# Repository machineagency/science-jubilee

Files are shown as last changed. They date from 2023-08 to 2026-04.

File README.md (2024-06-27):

# 🔬🧪 Science Jubilee ⚡⚙️
### Controlling Jubilees for Science!

<!-- [![Built Status](https://api.cirrus-ci.com/github/<USER>/science-jubilee.svg?branch=main)](https://cirrus-ci.com/github/<USER>/science-jubilee) -->

<!--- [![Coveralls](https://img.shields.io/coveralls/github/machineagency/science-jubilee/main.svg)](https://coveralls.io/r/machineagency/science-jubilee) --->

<!-- [![Conda-Forge](https://img.shields.io/conda/vn/conda-forge/science-jubilee.svg)](https://anaconda.org/conda-forge/science-jubilee) -->




> Use an open-source toolchanger to do science



This repository hosts files to build and control a [Jubilee](https://jubilee3d.com/index.php?title=Main_Page) for scientific applications. The core of the software is a Python interface for Jubilee to navigate labware installed in the machine. We currently provide assembly instructions, control software, and examples for various tools including OT-2 pipettes, syringes, and cameras. While these tools might cater exactly to your planned use case, they most likely will not! We share these files as a starting point rather than an endpoint: we also provide instructions for developing new tools and associated software for controlling them. We hope you will build new tools for your application and contribute them back to the community for others to use and extend 🛠️

_Check out the [Documentation](https://science-jubilee.readthedocs.io/en/latest/index.html) to get started!_

## Overview
### Hardware
This repository is designed to be used with the Jubilee platform, outfitted with tools for laboratory automation. Jubilee an open-source & extensible multi-tool motion platform—if that doesn't mean much to you, you can think of it as a 3D printer that can change its tools. You can read about [Jubilee](https://jubilee3d.com/index.php?title=Main_Page) more generally at the project page.

### Software
The software here is intended to control Jubilee from Python scripts or Jupyter notebooks to design and run experiments. The folders are organized as follows:
```
calibration/                 # notebooks to support machine & tool setup/calibration
tool_library/                # design files, assembly instructions, & configuration info for all tools & plates
src/
└── science_jubilee/
    ├── Machine.py               # jubilee machine driver
    ├── tools/
    │   ├── configs/             # all tool configs are here
    │   ├── Tool.py              # base tool class
    │   └── ...                  # all tool modules are here
    ├── decks/
    │   ├── configs/             # all deck configs are here
    │   ├── Deck.py              # base deck class
    │   └── ...                  # all deck modules are here
    └── labware/
        ├── labware_definitions/ # all labware definitions are here
        └── Labware.py           # base labware class
```

### Labware and Wetware
The basic functionality supported by this software is intended to be used with a custom deck which accommodates up to 6 standard sized microplates.

### Using science_jubilee
You can import and use `science_jubilee` modules by importing the modules you need at the top of your python file/notebook. For example, if we want to pipette using a lab automation deck, we might write:
```python
from science_jubilee.Machine import Machine                             # import machine driver
from science_jubilee.decks.LabAutomationDeck import LabAutomationDeck   # import lab automation deck module
from science_jubilee.tools.Pipette import Pipette                       # import pipette module
...                                                                     # you can import other decks/tools here, or make your own!
```
We can then make use of these modules in our code:
```python
m = Machine()                                                  # connect to your jubilee
deck = m.load_deck(deck_config_name)                           # setup your deck
tip_rack = deck.load_labware(opentrons_96_tiprack_300ul, 0)    # install an opentrons tip rack in slot 0 of the deck
pipette = Pipette(<index>, <name>, <tip_rack>, <config_file>)  # instantiate your pipette tool
m.load_tool(pipette)                                           # configure the pipette for use on the machine
...
```

<!-- pyscaffold-notes -->

## Note

This project has been set up using PyScaffold 4.5. For details and usage
information on PyScaffold see https://pyscaffold.org/.

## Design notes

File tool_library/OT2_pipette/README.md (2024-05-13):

# Opentrons OT2 Pipette
This tool can be assembled using two different tool assemblies which only differ by fabrication techniques (i.e., 3D printed only or 3D + Laser Cut)

## Wiring

For wiring we suggest using the following items:
* 1x 10-Pin (2x5) Female IDC 2.54mm Pitch [Connectors](https://www.amazon.com/gp/product/B07W5C4P6Z/ref=ppx_yo_dt_b_asin_title_o01_s00?ie=UTF8&psc=1)
* 1x 2.54mm Connectors, 10 Wire [Flat Ribbon Cable](https://www.amazon.com/gp/product/B08435GF42/ref=ppx_yo_dt_b_asin_title_o09_s00?ie=UTF8&psc=1)

For wiring information, follor the instructions found in `assembly_docs/OT2_Wiring_Diagram.pdf`

## Fabrication Files

Fabrication files for each of the two version of the tool assembly can be found in the `designs/` folder. There you can also find the tool post assembly.

## Duet Configuaration

Refer to the `duet_config/OT2_Pipette_Configuration.md` file for more information on how to update your machine's `config.g` file to control the pipettor.

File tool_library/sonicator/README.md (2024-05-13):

# Sonicator

This tool can be assembled and interfaced in different ways. You can find below a list of necessary components

## Hardware Checklist

### Sonicator Tool
* Q125 Sonicator Horn
* Sonicator Probe (various probe sizes, including pn: 4423, pn: 4422, and pn: 4435)
* Sonicator Control PCB, pn: KITVC1025 (20kHz) or pn: KITVC1045 (40kHz)
* Sonicator Wiring Harness
    * 1x [Molex: 0022552102](https://www.digikey.com/en/products/detail/molex/0022552102/303176)
    * 3x [Molex: 0016020086](https://www.digikey.com/en/products/detail/molex/0016020086/467788)
    * 1x [McMaster-Carr: 7243K117](https://www.mcmaster.com/7243K117/) for the sonicator horn wiring
    * 1x [McMaster-Carr: 7243K122](https://www.mcmaster.com/7243K122/) for the sonicator horn wiring
    * 1x [Digikey: ED10562-ND](https://www.digikey.com/en/products/detail/on-shore-technology-inc/OSTVN03A150/1588863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)

### Raspberry Pi Pico Microcontroller
One of the ways to interface with the sonicator control PCB board is using a Raspberry Pi Pico microcontroller. This solution allows the user to interface the tool through their computer directly, instead of relying on a Raspberry Pi SBC. To set up the RP2040 pico, the instructions and necessary files can be found in the `rp2040` folder.

For this solution, the following items are required:
* 1x [Raspberry Pi Pico RP2040 microcontroller](https://www.raspberrypi.com/documentation/microcontrollers/raspberry-pi-pico.html)
* 1x [Adafruit MCP4725 12-bit DAC](https://www.adafruit.com/product/935)
* 1x [Half-size Breadboard](https://www.adafruit.com/product/64), alternatively you can also purchase a [Half-size soldering breadboard](https://www.digikey.com/en/products/detail/sparkfun-electronics/PRT-12070/5230951)
* 1x [Breadboard wire bundle](https://www.adafruit.com/product/153)
* 1x [2N7000 MOSFET](https://www.digikey.com/en/products/detail/onsemi/2N7000/244278)
* 1x [100𝜇F Capacitor](https://www.amazon.com/100uF-105%C2%B0C-Aluminum-Electrolytic-Capacitor/dp/B07D6WDQMV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)
* 1x [4.7kΩ Resistor](https://www.adafruit.com/product/2783)

Below is a schematics for the assembly:
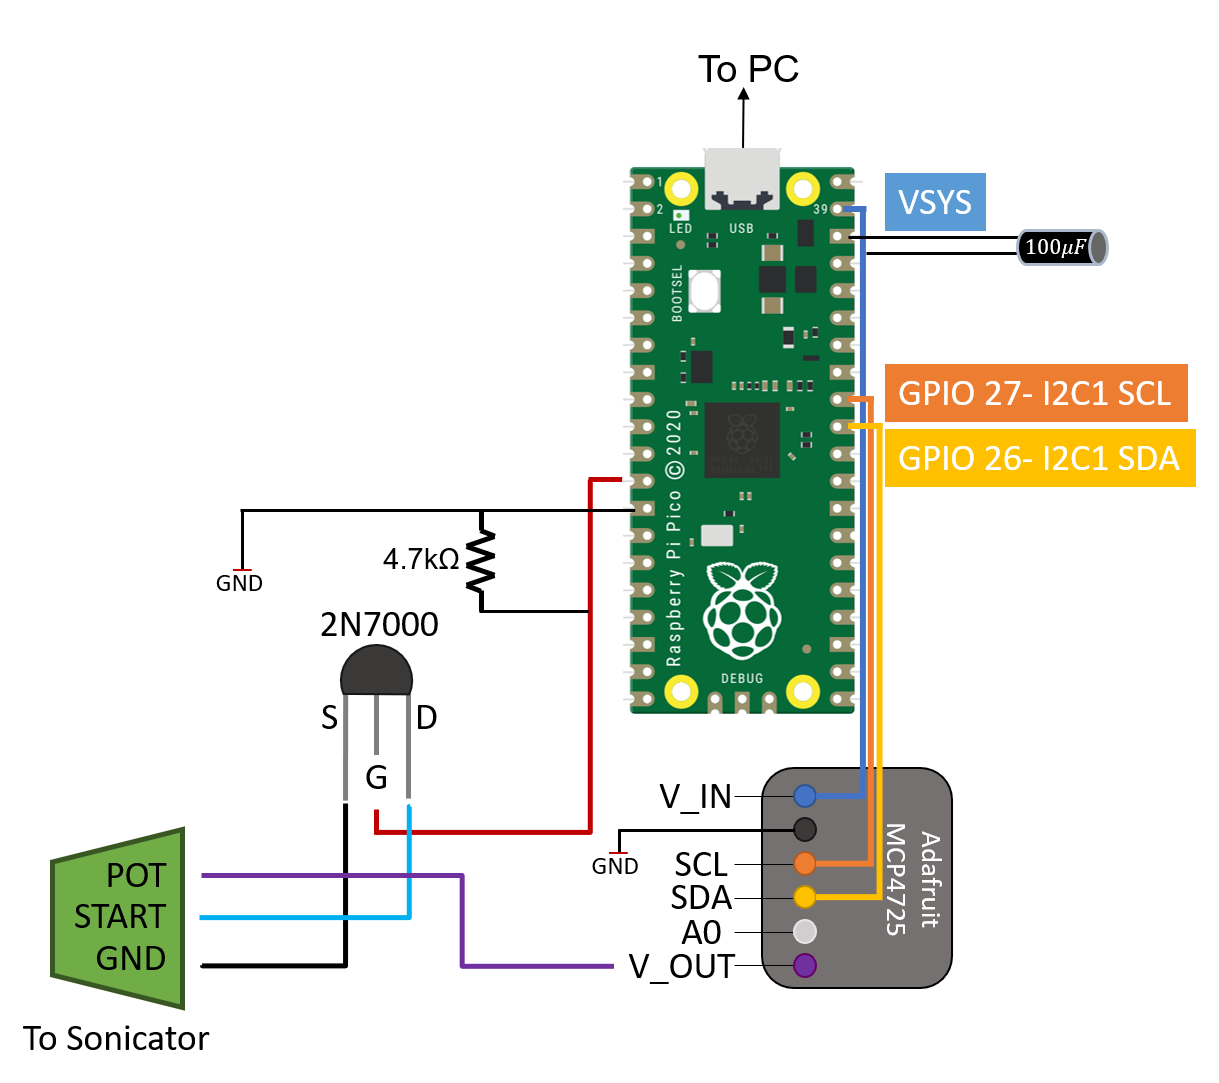
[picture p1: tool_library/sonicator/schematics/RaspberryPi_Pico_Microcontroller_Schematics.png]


### Raspberry Pi SBC and PCB Hat
If you are interfacing your Science Jubilee using a Raspberry Pi singleboard computer, you will need to order and assemble the *sonicator PCB* hat. The instructions and necessary files can be found in the `pcb_hat` folder. The Sonicator Pi Hat will be attached to the Pi and connected to the Sonicator Control PCB.
A schematics can be found [here](https://github.com/machineagency/science-jubilee/tree/main/tool_library/sonicator/schematics/RaspberryPi_PCB_Hat_Schematics.pdf)
This solution is the original imlementaiotn of this tool in combination with a Jubilee platform. This project was also known as the *Sonication Station*. The original repository is [here](https://github.com/machineagency/sonication_station).

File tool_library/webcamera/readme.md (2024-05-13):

# Raspberry Pi WebCamera

The WebCamera tool is just a Raspberry Pi Camera set up to support a livestream video over the web.
This can be used to monitor samples/objects on the deck. Alternatively, it can also be used to collect images of samples as a Tool hosted on your Jubilee.

## Necessary Hardware:
* A Raspberry Pi SBC
* Raspberry Pi camera (V2 or V3)
* An arducam pi camera HDMI extension kit along with an [hdmi cable](https://www.amazon.com/Arducam-Extension-Module-Raspberry-Specific/dp/B06XDNBM63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*)
* Hdmi cable (at least 3ft)
* Ethernet cable ( at least 3ft)

## Ring Light (Optional):
* Side emitting COB LED lights (e.g., [LED lights](https://www.amazon.com/dp/B0CG9H983Z?psc=1&ref=ppx_yo2ov_dt_b_product_details))

To control the LED lights, you can use the Duet board by plugging them into a 'fan' port. On your main Duet board you can for example `out5` or `out6` ports.
1. Cabling :

* connect the *positive LED lead* into the *"V_OUTLC2 +"* pin
* connect the *negative LED lead* into the *"out5 -"* pin

2. Duet Config

Define the LED lights into the `config.g` file of your jubilee by using the `M950` command:
`M950 P0 C"0.out5"` # P{LED index}; C{port name}

To turn on and off the light you will use the `M42` command:
`M42 P0 S0.5` # P{LED index}; S{intensity}, ranges from 0 (off) to 1 (max intensity)
    Note: this optin is alreadyimplement in the tool.WebCamera mdule. You will need to define the LED index in the tool config file and set `light=True` and `light_intensity= float` in the `capture_image()` method.

## RaspberryPi Set up

* Install raspberry pi os on a Raspberry Pi 4GB of ram should be fine - we’re just running a web server on it to stream videos
* Connect the camera using the hdmi cable extension kit. Make sure the camera works at this stage before trying to get the web server to work.
* Clone the `PI-camera-stream-flask` repo onto your raspberry pi. Brenden Pelkies’s fork has a few updates that makes it work with jubilee. [Github repository](https://github.com/brendenpelkie/pi-camera-stream-flask)
* Follow the instructions in the readme of the repo to get the camera up and running.
* Connect the raspberry pi to your local network and manually specify an IP address for it. To complete these steps, there are a lot of tutorials. [Here is one](https://www.makeuseof.com/raspberry-pi-set-static-ip/)
* Connect to your raspberry pi camera by navigating to `http:/<yourPi_IPaddress>:50001`. You should now be able to see a live feed video displayed with some buttons and a target pattern.

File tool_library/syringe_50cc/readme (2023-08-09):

this is where 50cc syringe files will be

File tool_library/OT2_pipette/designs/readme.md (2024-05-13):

Fabrication files for the OpenTrons 2 pipette tool.

Note: there are currently 2 versions of the tool holder. They only differ by the fabrication techniques, not functionality.
* 3D printed designs only
* 3D printed & Laser cut designs

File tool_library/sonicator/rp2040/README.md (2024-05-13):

# Setting up the RP2040 Pico microcontroller

The projects implements the [Raspberry Pi Pico C/C++ SDK](https://datasheets.raspberrypi.com/pico/getting-started-with-pico.pdf).

To start, you should clone the GitHub repository for the [Pico-sdk](https://github.com/raspberrypi/pico-sdk) in your *PROJECT_DIRECTORY* and set up all the required submodules by running the following command in the sdk directory:

`git submodule update --init --recursive`

You can now follow the instructions to *Quick-start your own project*.

The `CMakelists.txt`, as well as the `main.c` files can be found here and should be placed in your *PROJECT_DIRECTORY* too.

## Compile the Firmware
Create a `/build` directory and navigate to it, then run the following commands:

`cmake ..`

This creates all the files required to later create the executable `.uf2` files. You can do so by running :

`make`

## Upload the Firmware onto the RP2040
Load the Pico in BOOTSEL mode and plug it into your computer's usb. Now, you can drag-and-drop the generated `.uf2` file into the mass storage device representing the Pico. It should now be automatically ejected and ready to use.

## Editing the Firmware
You can edit the `main.c` file to change which pins you are using to connect to the MCP4725 DAC or which GPIO pin turns on/off the sonicator.
If you do so, you will need to re-run the following command:

`make`

    Note: if you make changes to the `CMakeLists.txt` file, you will need to re-create the `/build` folder, navigate to it, and run `cmake ..` , followed by `make` too.

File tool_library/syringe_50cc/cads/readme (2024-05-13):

These are the solidworks files for the 500 cc syringe

If you are going to make edits, please download all of the cad files.
The base plate is modeled using the syringe cad and will only work if that file is in the same folder

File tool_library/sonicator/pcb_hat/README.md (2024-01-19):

Note: see [machineagency/sonication_station](https://github.com/machineagency/sonication_station) for more details for this solution.

# Sonicator PCB

This PCB attaches on top of the Raspberry Pi enabling its GPIOs to control the Sonicator.

## Fabrication

To make this pcb, you'll need to send files (usually gerbers) out to a PCB Fab house of your choice.
Here are some options:

* [OSH Park](https://oshpark.com/) will actually natively accept **.kicad\_pcb** files directly. (This is probably the easiest option.)
    * [instructions for gerber generation](https://docs.oshpark.com/design-tools/kicad/generating-kicad-gerbers/)
* [PCBWay](http://pcbway.com/)
    * [instructions for gerber generation](https://www.pcbway.com/blog/help_center/Generate_Gerber_file_from_Kicad.html)
* Bay Area Circuits has a No-Silk-No-Soldermask 24-hour [Bare Bones Special](https://bayareacircuits.com/prototype-printed-circuit-boards-pcbs/) for time crunched prototypes.

## Assembly

This PCB can be assembled by hand with some tweezers, a microscope (or cheap microscope webcam), and, optionally, a stencil.
Parts will need to be ordered from the BOM.
(You can regenerate the BOM from the native Kicad files.)

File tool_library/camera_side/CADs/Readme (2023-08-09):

Solidworks files for the side facing camera

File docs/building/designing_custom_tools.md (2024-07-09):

---
title: Designing Custom Tools
---

(designing-custom-tools)=
# Designing Custom Tools

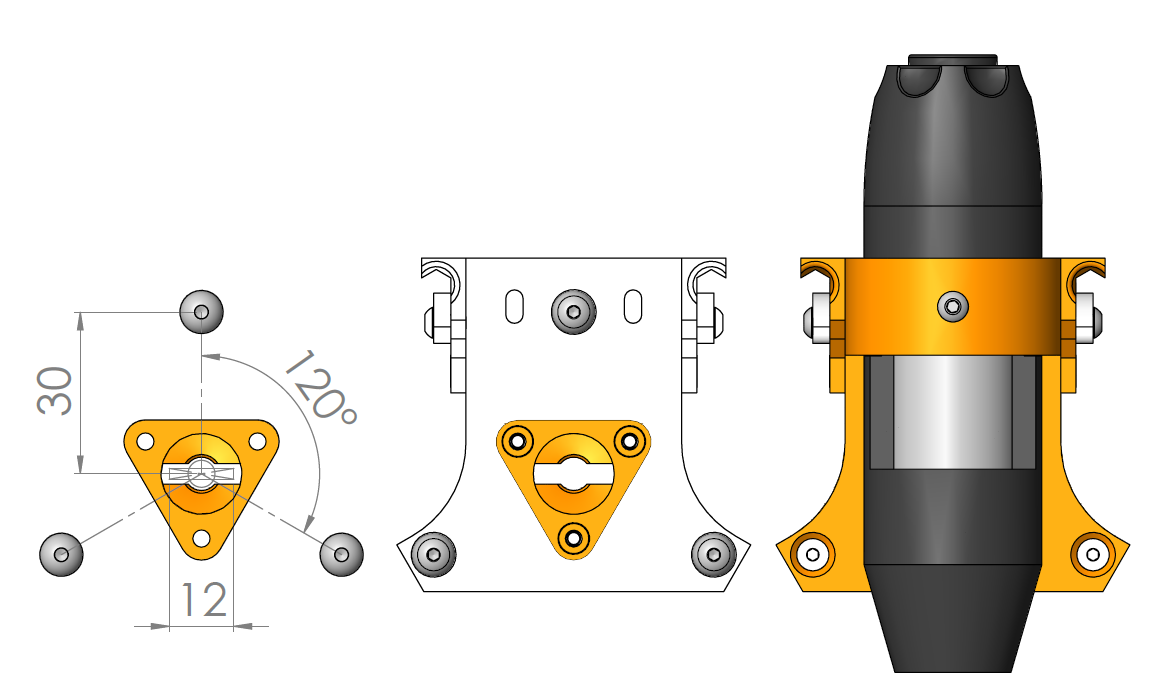
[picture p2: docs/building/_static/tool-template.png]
```{figure} _static/tool-template.png
:scale: 50 %

The shortcut to 3D modeling a tool with the right placements is to simply build on top of the CAD files in [the template folder](https://github.com/machineagency/jubilee/tree/main/tools/jubilee_tools/tool_template).
```

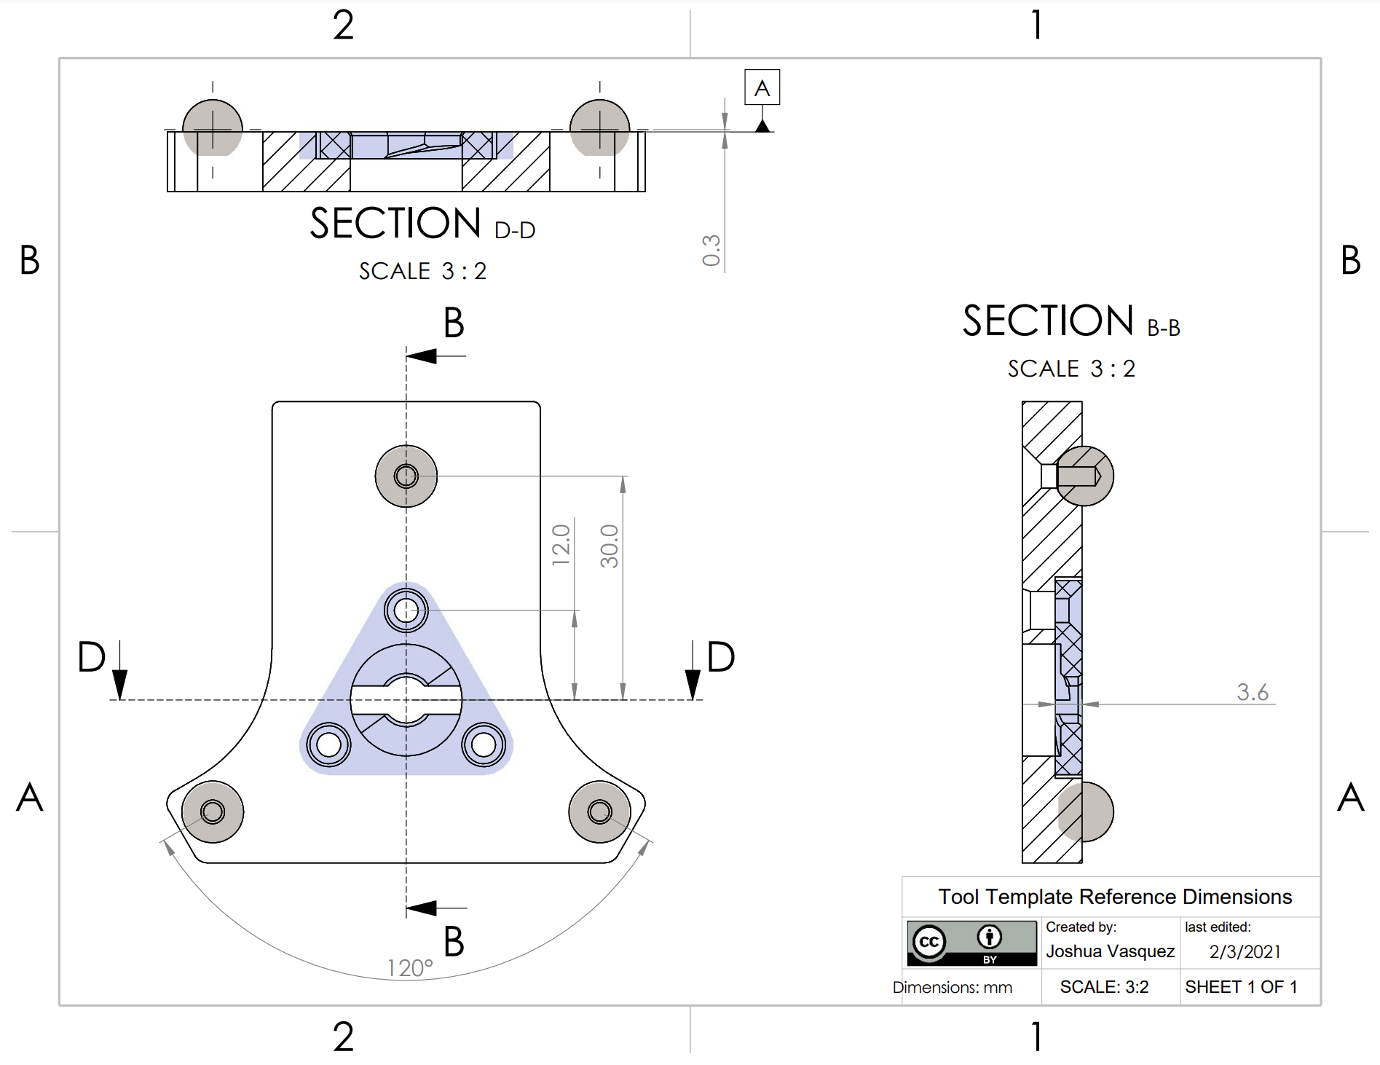
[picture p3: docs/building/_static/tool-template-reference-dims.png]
```{figure} _static/tool-template-reference-dims.png
:scale: 50 %

starting from scratch is also straightforward. To create a custom tool that locks into Jubilee's carriage, you must place the tool balls and the wedge plate in a specific location, specified in the [Tool Template Reference Dimensions](https://github.com/machineagency/jubilee/raw/main/tools/jubilee_tools/tool_template/references/tool_template_reference_dimensions.pdf), shown above.
```

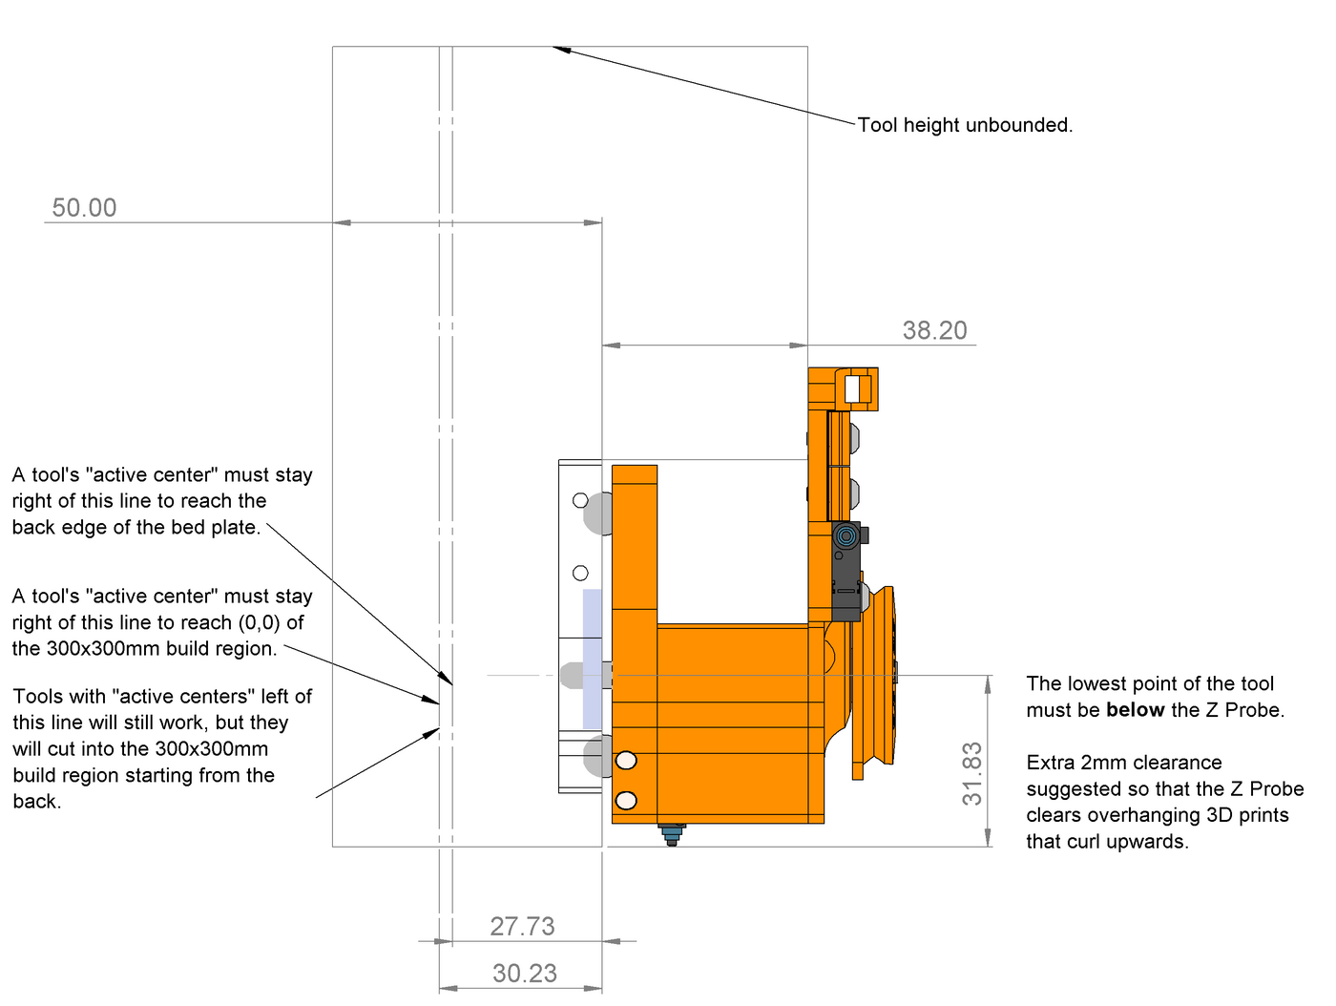
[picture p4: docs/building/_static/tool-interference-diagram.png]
```{figure} _static/tool-interference-diagram.png
:scale: 50 %

There are a few size constraints that may influence your tool's shape, shown above. A number of example tools are shown in the [Tool Interface Diagram PDF](https://github.com/machineagency/jubilee/raw/main/frame/references/tool_interface_diagram.pdf). Note that many of these constraints are soft. Using longer dowel pins on the parking post will allow for deeper tools. Also, moving the tool's active center past the leftmost line will result in a working tool that simply has a bit less Y-axis travel.
```

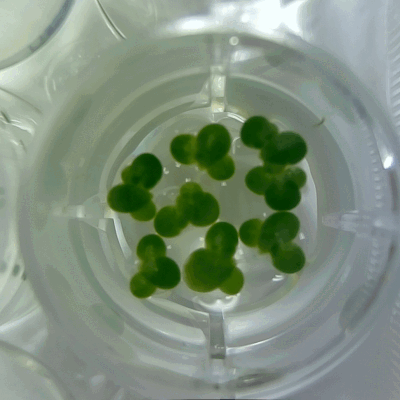
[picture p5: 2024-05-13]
docs/_static/lm-loop-400x400.gif

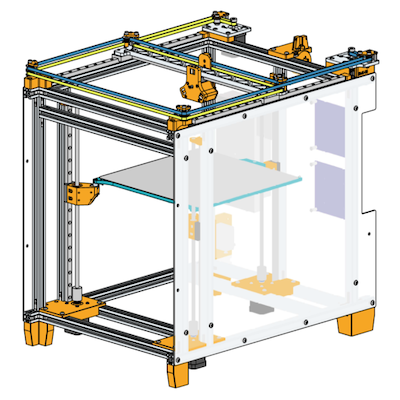
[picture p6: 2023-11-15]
docs/_static/jubilee.png

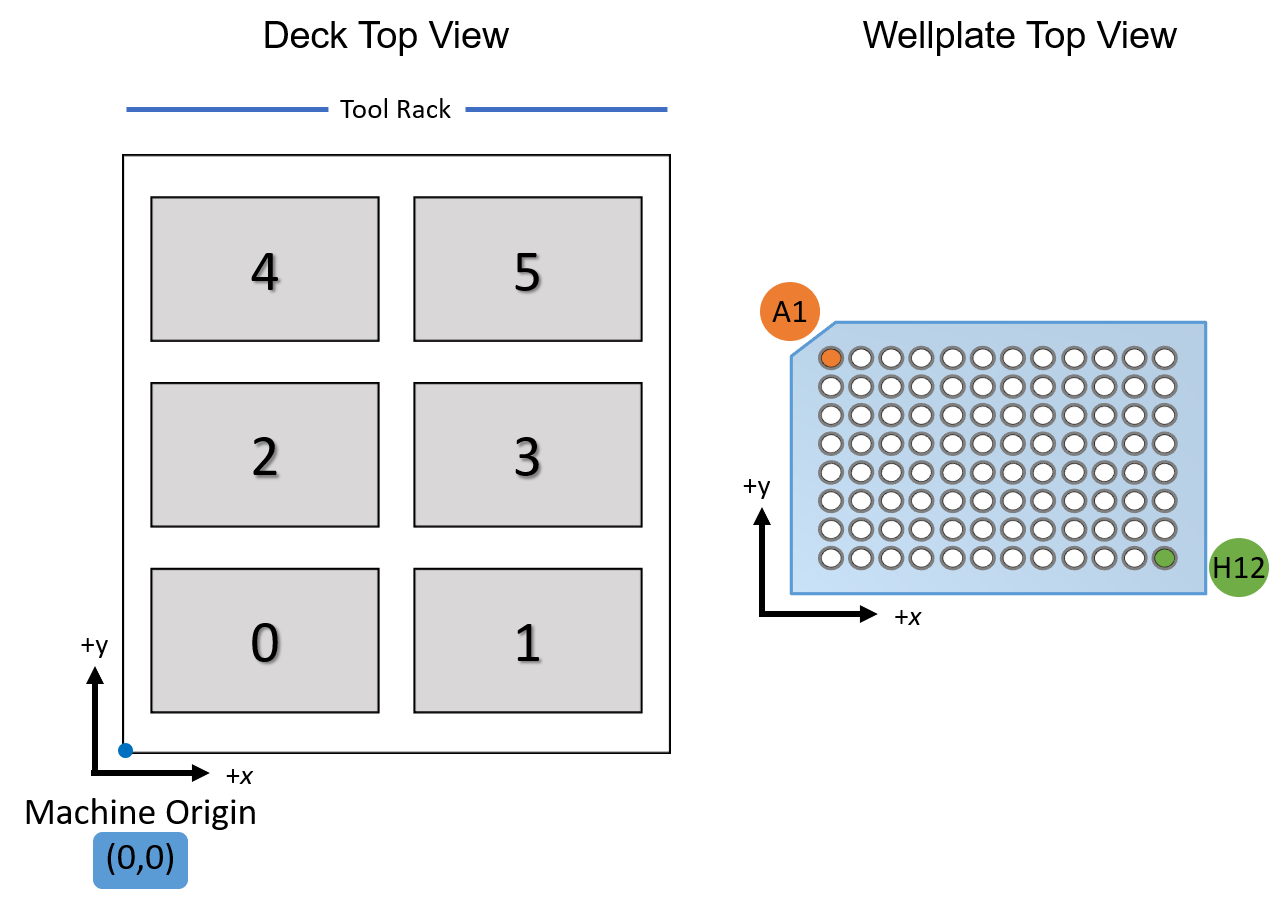
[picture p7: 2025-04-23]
docs/notebooks/images/deck_layout.png

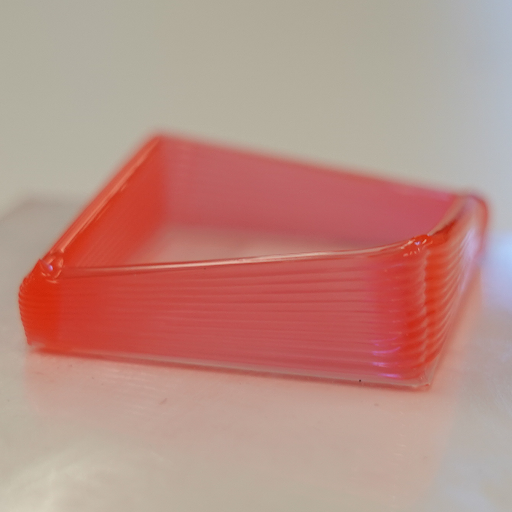
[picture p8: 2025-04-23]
docs/notebooks/images/gel-example.png

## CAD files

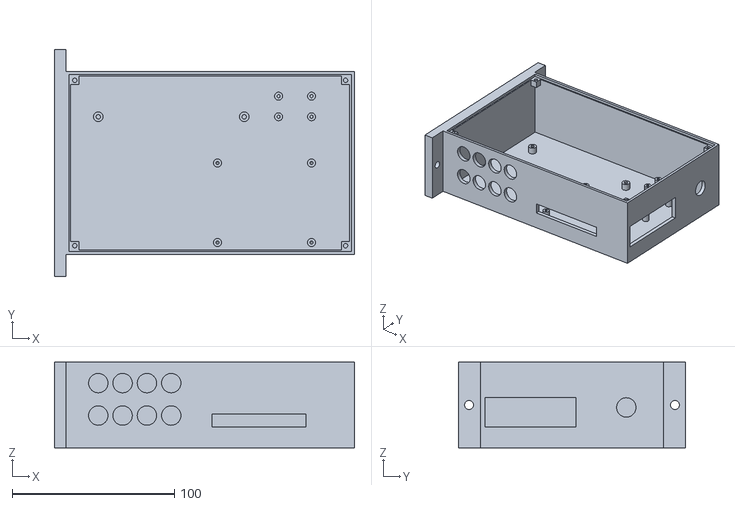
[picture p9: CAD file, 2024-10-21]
tool_library/HTTPsyringe/designs/control_box/stl/module_main v2.stl
185.0 x 139.7 x 53.0

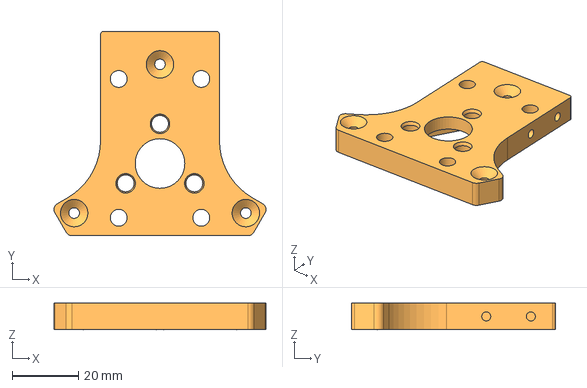
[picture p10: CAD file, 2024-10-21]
tool_library/HTTPsyringe/designs/syringe_tool/shared/tool_template_assembly v1.step
64.2 x 61.8 x 8.03 mm

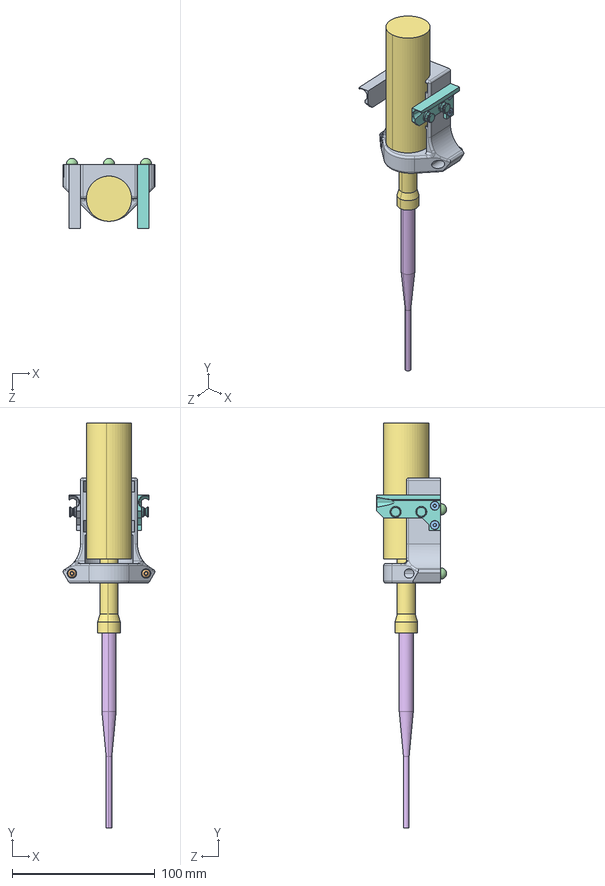
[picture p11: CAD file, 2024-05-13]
tool_library/sonicator/designs/sonicator_tool_assembly.STEP
64.4 x 284.1 x 49.3 mm
sonicator_base_tool_plate_tool plate
wedge_plate
m3_6mm_flathead_screw_92125A126_92125A126 x 7
m3_threaded_ball x 3
m3_heat_set_insert_94180A331_94180A331 x 3
q125_sonicator_head
sonicator_tool_wing_Standard Right Tool Wing
sonicator_tool_wing_Standard Left Tool Wing
m3_6mm_buttonhead_screw_92095A179_92095A179 x 3

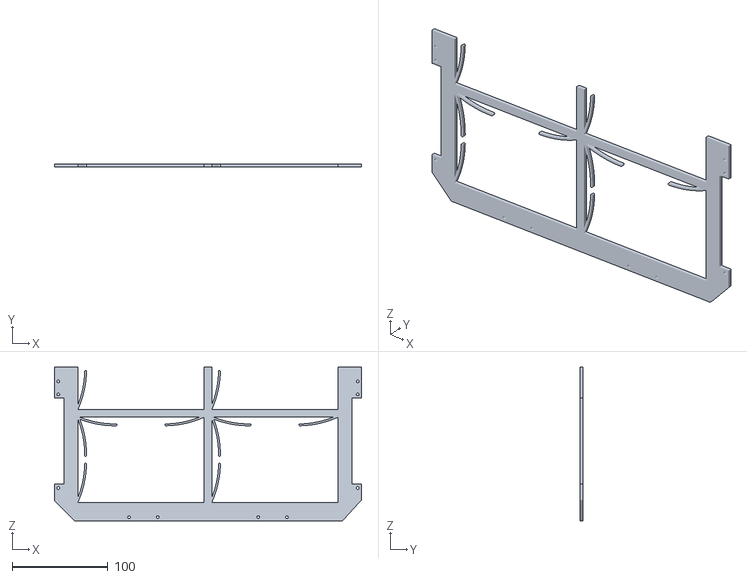
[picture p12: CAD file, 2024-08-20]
tool_library/bed_plate/fabrication_files/deck_top.stl
321.0 x 3.17 x 161.0

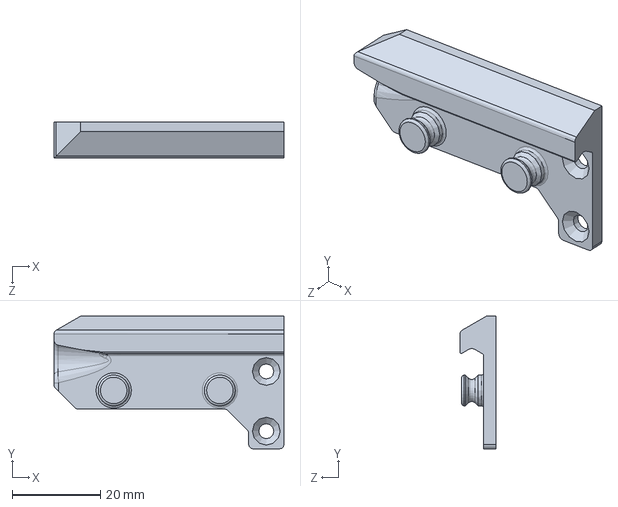
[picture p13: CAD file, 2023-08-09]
tool_library/camera_side/CADs/side_camera_tool_wings.SLDPRT
52.0 x 30.0 x 8.20 mm

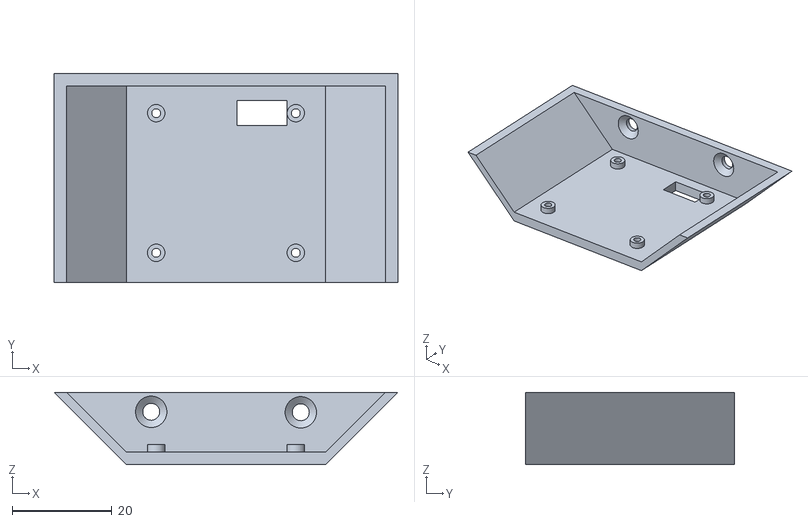
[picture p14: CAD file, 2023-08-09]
tool_library/camera_side/STLs/side_camera_connector.STL
69.0 x 42.0 x 14.5

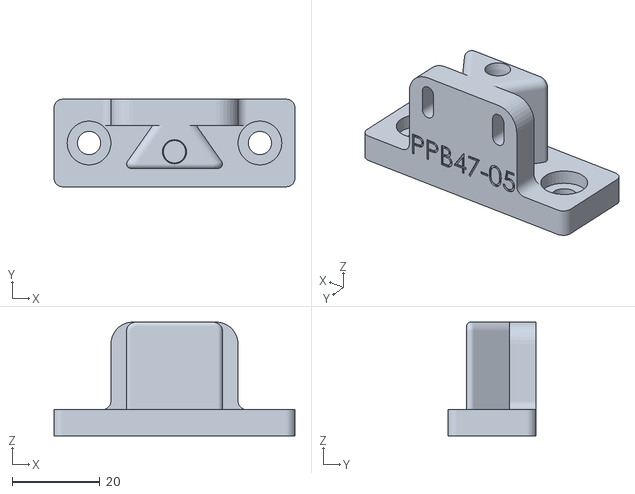
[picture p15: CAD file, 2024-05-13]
tool_library/camera_top/parking_post_base_47mm.STL
55.0 x 20.0 x 26.0

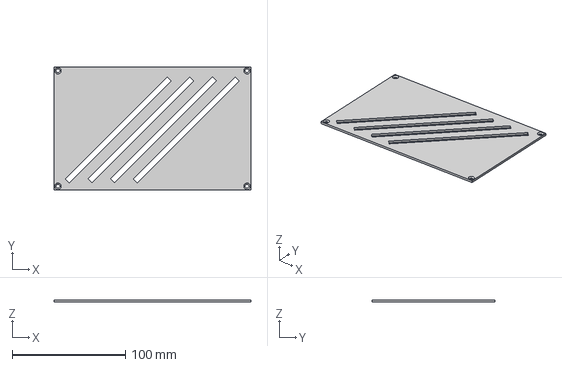
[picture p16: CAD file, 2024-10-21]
tool_library/HTTPsyringe/designs/control_box/cads/module_lid v3.step
174.0 x 109.0 x 2.00 mm

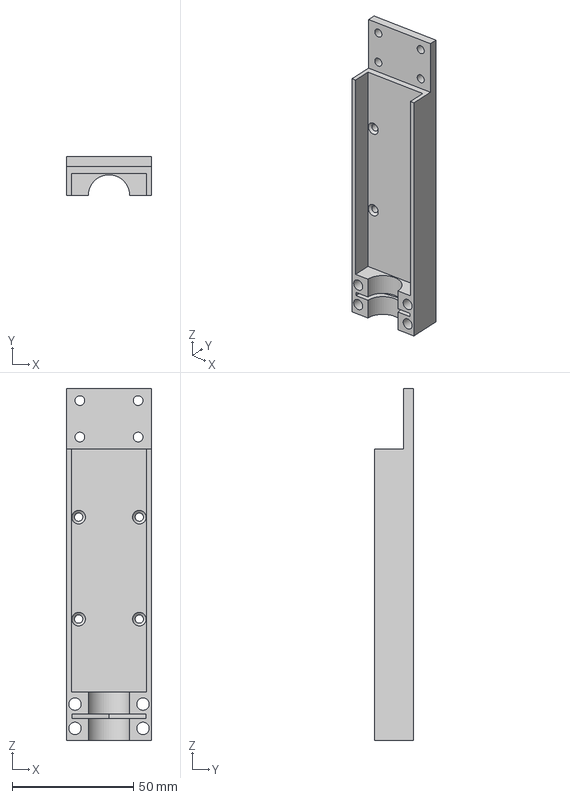
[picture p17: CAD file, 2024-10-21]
tool_library/HTTPsyringe/designs/syringe_tool/10cc_tool/cads/platform_bottom_10cc v2.step
35.0 x 16.0 x 145.0 mm

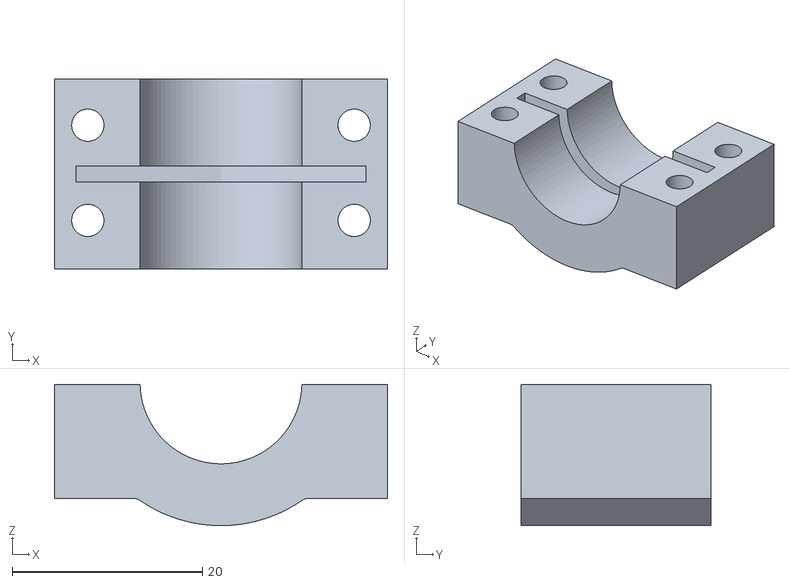
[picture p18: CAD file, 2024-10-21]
tool_library/HTTPsyringe/designs/syringe_tool/10cc_tool/stl/cover_10cc v4.stl
35.0 x 20.0 x 14.8

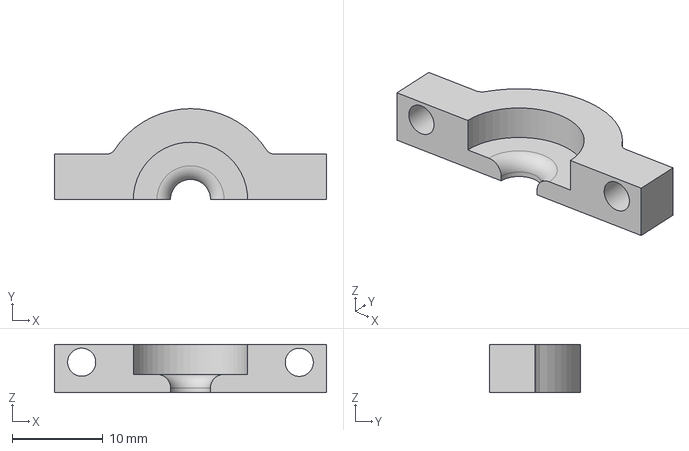
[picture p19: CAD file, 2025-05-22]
tool_library/HTTPsyringe/designs/syringe_tool/1cc_HamiltonGlass/cads/holder_clamp_1cc_hamilton v4.step
30.0 x 10.0 x 5.30 mm

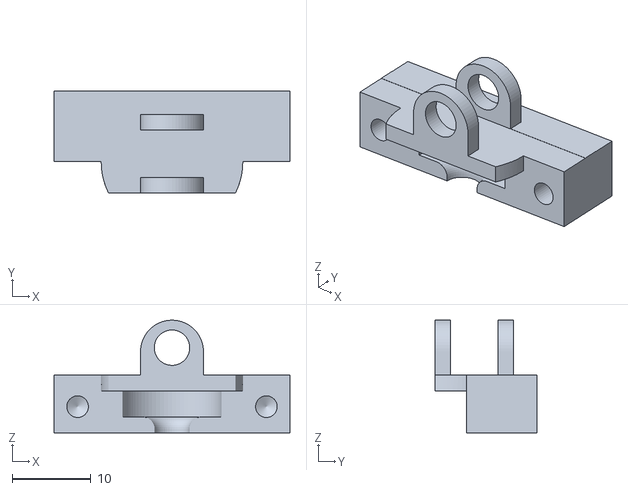
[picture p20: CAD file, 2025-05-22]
tool_library/HTTPsyringe/designs/syringe_tool/1cc_HamiltonGlass/stl/holder_1cc_hamilton v3.stl
30.0 x 13.0 x 14.3

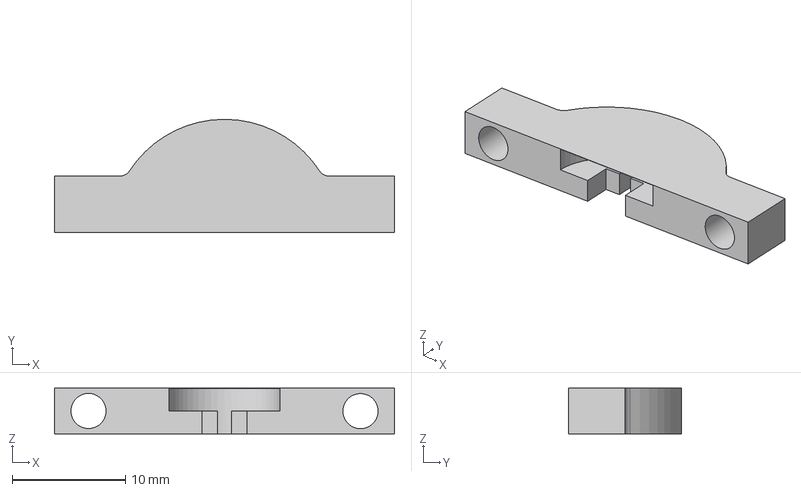
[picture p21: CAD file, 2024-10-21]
tool_library/HTTPsyringe/designs/syringe_tool/1cc_tool/cads/holder_clamp v2.step
30.0 x 10.0 x 4.03 mm

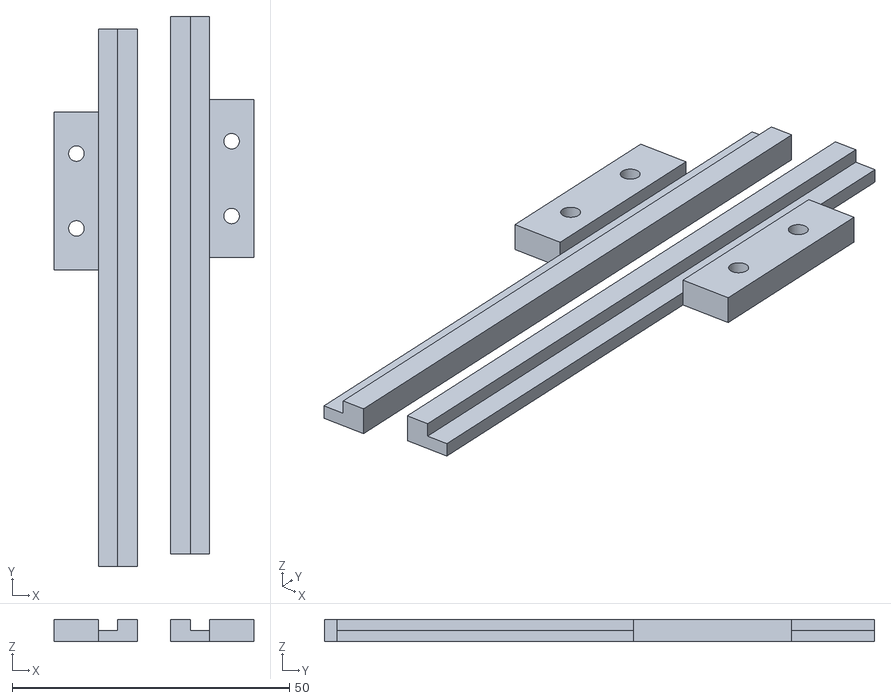
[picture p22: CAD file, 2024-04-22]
tool_library/OT2_pipette/designs/3D_LaserCut/L&R_guide_rail.STL
36.0 x 99.2 x 4.00

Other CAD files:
tool_library/HTTPsyringe/designs/control_box/cads/module_main v2.step
tool_library/HTTPsyringe/designs/syringe_tool/1cc_tool/stl/holder_clamp v2.stl
tool_library/OT2_pipette/designs/3D_only/OT2_Pipette_Wings.stl
tool_library/OT2_pipette/designs/Tool_post/OT_post_base.STL
tool_library/HTTPsyringe/designs/control_box/cads/module_lid v3.f3d
tool_library/HTTPsyringe/designs/control_box/cads/module_main v2.f3d
tool_library/HTTPsyringe/designs/control_box/stl/module_lid v3.stl
tool_library/HTTPsyringe/designs/syringe_tool/10cc_tool/cads/cover_10cc v4.f3d
tool_library/HTTPsyringe/designs/syringe_tool/10cc_tool/cads/cover_10cc v4.step
tool_library/HTTPsyringe/designs/syringe_tool/10cc_tool/cads/holder_10cc v2.f3d
tool_library/HTTPsyringe/designs/syringe_tool/10cc_tool/cads/holder_10cc v2.step
tool_library/HTTPsyringe/designs/syringe_tool/10cc_tool/cads/holder_clamp v2.f3d
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

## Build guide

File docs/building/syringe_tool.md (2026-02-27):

---
title: Syringe Tool
---

(syringe-tool)=
# Syringe Tool

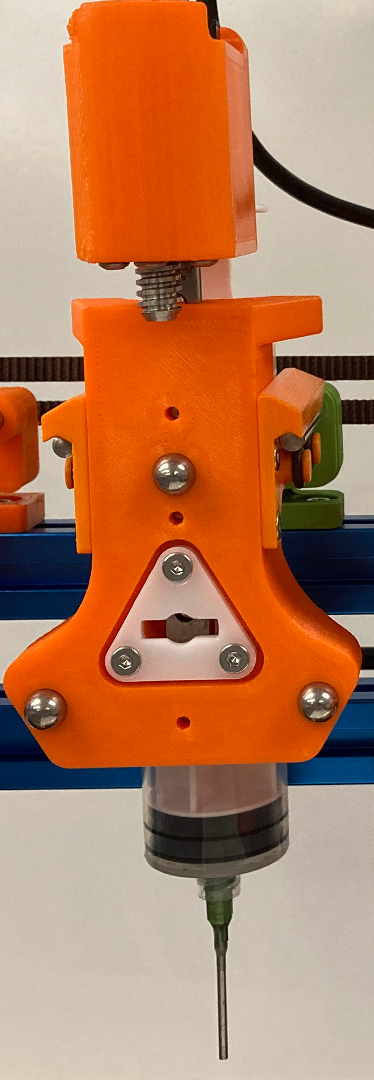
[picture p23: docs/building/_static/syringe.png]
```{figure} _static/syringe.png
:scale: 25 %

50 cc syringe parked on a Jubilee
```

See the [10cc Syringe tool](https://jubilee3d.com/index.php?title=10cc_Syringe_Tool) documented on the Jubilee project page. Here, we provide files to accommodate a larger 50cc syringe.

## Parts to Buy

- Syringe (10cc or 50cc)
- The full shopping list can be found [here](https://docs.google.com/spreadsheets/d/1Fj20bxpdoopTrS_6ojMFQcdhQe556lmoZU1JOpwKWVU/edit?usp=sharing) and is the same for both the 10cc and 50cc syringe.

## Parts to 3D Print

- Parts to print for a 50cc syringe can be found [here](https://github.com/machineagency/science-jubilee/tree/main/tool_library/syringe_50cc/STLs). See above for 10cc syringe.
- SolidWork files for the 50cc syringe parts are [here](https://github.com/machineagency/science-jubilee/tree/main/tool_library/syringe_50cc/cads).

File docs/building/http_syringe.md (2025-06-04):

---
title: Digital Pipette HTTP Syringe
---

(http-syringe)=
# Digital Pipette HTTP Syringe Tool

The Digital Pipette HTTP Syringe tool is one adaptation of the [Digital Pipette tool developed by Naruki Yoshikawa et. al](https://pubs.rsc.org/en/content/articlehtml/2023/dd/d3dd00115f) to the Jubilee platform. This adaptation adds a Jubilee tool plate and parking post wings to the tool and adapts the control interface to integrate with the science-jubilee library. This tool uses a linear servo actuator mounted in a 3D printed frame to drive a disposable plastic syringe. The servo is controlled through a raspberry pi, which exposes an HTTP interface to interact with the science-jubilee library client for this tool. This tool is similar in principle to the other Jubilee [syringe tool](./syringe_tool.md). This tool uses linear servo motors instead of stepper motors and leadscrews. This makes this version lighter, easier to build, and extensible to a multi-tool setup with fewer duet boards. The stepper motor version will provide more force for handling viscous liquids.

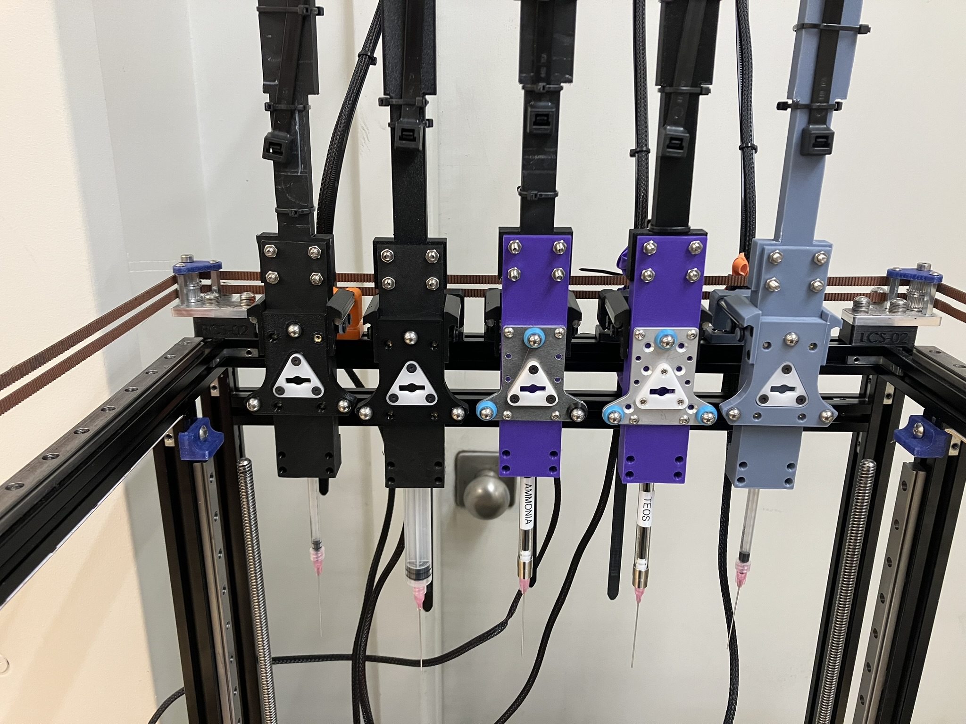
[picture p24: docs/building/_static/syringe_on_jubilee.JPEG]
```{figure} _static/syringe_on_jubilee.JPEG
```

### Pros of this tool
- Low cost liquid handling - this tool can be built for a per-tool cost of around $80USD, with some additional control hardware costs spread across multiple tools. This is much cheaper than the [OT2 Pipette tool](./pipette_tool.md).
- Swappable liquid-contacting parts. Everything that comes into contact with liquids and their vapors is fast and easy to swap out, so you don't need to worry about damaging expensive equipment with incompatible solvents. You do still need to worry about solvent compatibility for safety and experimental fidelity reasons.
- Choice of syringe tips - this tool uses syringes with Luer-lock tips, which is the standard interface for syringe tips. This gives you access to a wide range of tips/needles for various purposes. Sharp, blunt, flexible, stout, long, short - there are endless options out there.
- Potentially faster batch dispensing compared to traditional pipette tool, especially for bulk liquid quantities
- No headspace volume. This tool allows you to remove all air from the plunger-barrel-liquid system. This results in better performance with volatile liquids (no headspace evaporation leading to dripping and inaccurate dispense) and better performance when injecting liquids into sealed containers, such as when using pre-slit silicone septa to manage evaporation

### Cons of this tool

- lower accuracy and precision. Performance is lower than the OT2 pipette for water.
- No disposable pipette tips. This tool places liquid to be transferred in direct contact with the syringe barrel. To perform multi-liquid transfers, multiple tools or a thorough rinse process are needed.

## Parts list

This Jubilee adaptation of the tool uses a single control box to manage several individual syringe tools. The linear servos are driven off of raspberry pi GPIO pins, so in practice the number of tools will be limited by how many you can fit on a Jubilee. 5 is likely the maximum on a standard Jubilee V2. All printed parts are printed in PLA.

### For each tool

You will need one set of these parts for each indivdual tool you want to build.

#### Parts to purchase

| Description | Quantity per tool | Vendor 1 | Est. total cost |
| --- |--- | --- | --- |
| Linear servo actuator, Actuonix L16-100-63-6-R | 1 | [Actuonix](https://www.actuonix.com/l16-100-63-6-r) | $70 |
| M12 4-pin connector | 1 | [Lonlonty via Amazon](https://www.amazon.com/gp/product/B09YLP4K5W/ref=ox_sc_act_title_2?smid=A3EPS00U1KMPT0&th=1) | $4.50 per tool (sold in 4 pack) |
| M12 4-pin panel mount socket | 1 | [Lonlonty via Amazon](https://www.amazon.com/gp/product/B0BBQTDLHP/ref=ox_sc_act_title_3?smid=A3EPS00U1KMPT0&th=1) |$4.25 per tool (sold in 4 pack) |
| M3 brass heat set inserts | 12 | [Mcmaster](https://www.mcmaster.com/94180A361/) | $4.30 |
| 22g Hookup wire | 18 feet | Any brand is fine | $ 3? |
| 1/8" expandable wiring sleeve | 6ft | [Alex Tech via Amazon](https://www.amazon.com/gp/product/B074GN12PY/ref=ox_sc_act_title_1?smid=A2N7NRZ9X3BHHN&th=1) | $ 1 ($13/100 foot roll) |
| Misc. M3 and M4 hardware | varies | [Suggested kit to have on hand](https://www.amazon.com/gp/product/B07L9MMN9K/ref=ppx_yo_dt_b_search_asin_title?ie=UTF8&th=1) | $2ish |
| Jubilee tool vitamins (wedge plat and tool balls) | 1 set | Filastruder | |
| Butt splice connectors for 22g wire | many | [Digikey](https://www.digikey.com/en/products/detail/panduit-corp/BS18-M/447759) | $0.30/ea |

Syringes:

The current printed parts are designed to hold either a [1cc](https://www.amazon.com/gp/product/B07VF8CKGL/ref=ox_sc_act_title_5?smid=A18RDK02R6I57P&psc=1) or [10cc](https://www.amazon.com/10ml-Syringe-Only-Luer-Lock/dp/B01DARHDV8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) syringe. Specifically, they are designed around the ones listed. If you are using a different volume or brand, you may need to re-design the mounting interface. At the time of writing, both of the above listed options are out of stock, so shifting to a more reliable vendor may be worthwhile. There is also a version of the 1cc syringe tool designed to work with a Hamilton glass syringe [(PN 81320)](https://www.hamiltoncompany.com/laboratory-products/syringes/81320).

Tips: We use a variety of blunt-tip luer lock tips with our syringe tools. We like [these](https://www.amazon.com/PATIKIL-Dispensing-Industrial-Dispenser-Refilling/dp/B0D54JYHJW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) 20gauge, 50mm blunt tips for general liquid handling as they are stout enough to pierce silicone septa and long enough to aspirate liquid from the bottom of a 20cc scintillation vial.

#### Parts to print

##### Shared between 1cc and 10cc tool:

| Part Name | Quantity | Link | Print notes |
| --- | --- |--- |---|
| Tool platform upper | 1 | [platform_upper v5.stl](https://github.com/machineagency/science-jubilee/blob/main/tool_library/HTTPsyringe/designs/syringe_tool/shared/platform_upper%20v5.stl) | |
| Tool Template assembly | 1 | [tool_template_assembly v1.stl](https://github.com/machineagency/science-jubilee/blob/main/tool_library/HTTPsyringe/designs/syringe_tool/shared/tool_template_assembly%20v1.stl) | |
| Left tool wing | 1 | [left_tool_wing_v2.STL](https://github.com/machineagency/jubilee/blob/main/tools/jubilee_tools/tool_template/fabrication_exports/3d_printed_parts/left_tool_wing_v2.STL) | |
| Right tool wing |1 | [right_tool_wing_v2.STL](https://github.com/machineagency/jubilee/blob/main/tools/jubilee_tools/tool_template/fabrication_exports/3d_printed_parts/right_tool_wing_v2.STL)| |

##### For 1cc tool:

| Part Name | Quantity | Link | Print notes |
| --- | --- |--- |---|
| Tool platform lower 1cc | 1 | [platform_bottom_1cc v2.stl](https://github.com/machineagency/science-jubilee/blob/main/tool_library/HTTPsyringe/designs/syringe_tool/1cc_tool/stl/platform_bottom_1cc%20v2.stl) | |
| Barrel cover 1cc | 1 | [cover_1cc v3.stl](https://github.com/machineagency/science-jubilee/blob/main/tool_library/HTTPsyringe/designs/syringe_tool/1cc_tool/stl/cover_1cc%20v3.stl) | |
| Plunger holder 1cc | 1 | [holder_1cc v7.stl](https://github.com/machineagency/science-jubilee/blob/main/tool_library/HTTPsyringe/designs/syringe_tool/1cc_tool/stl/holder_1cc%20v7.stl) | Mind your supports and print orientation |
| Plunger holder clamp 1cc | 1 | [holder_clamp v2.stl](https://github.com/machineagency/science-jubilee/blob/main/tool_library/HTTPsyringe/designs/syringe_tool/1cc_tool/stl/holder_clamp%20v2.stl) | Mind your supports and print orientation |

Analogous versions for the hamilton glass syringe are also available in the github repo.

##### For 10cc tool:

| Part Name | Quantity | Link | Print notes |
| --- | --- |--- |---|
| Tool platform lower 10cc | 1 | [platform_bottom_10cc v2.stl](https://github.com/machineagency/science-jubilee/blob/main/tool_library/HTTPsyringe/designs/syringe_tool/10cc_tool/stl/platform_bottom_10cc%20v2.stl) | Should be printed flat side down |
| Barrel cover 10cc | 1 | [cover_10cc v4.stl](https://github.com/machineagency/science-jubilee/blob/main/tool_library/HTTPsyringe/designs/syringe_tool/10cc_tool/stl/cover_10cc%20v4.stl) | |
| Plunger holder 10cc | 1 | [holder_10cc v2.stl](https://github.com/machineagency/science-jubilee/blob/main/tool_library/HTTPsyringe/designs/syringe_tool/10cc_tool/stl/holder_10cc%20v2.stl) | Mind your supports and print orientation |
| Plunger holder clamp 0cc | 1 | [holder_clamp v2.stl](https://github.com/machineagency/science-jubilee/blob/main/tool_library/HTTPsyringe/designs/syringe_tool/10cc_tool/stl/holder_clamp%20v2.stl) | Mind your supports and print orientation |

### Control hardware

You will need one control module for each Jubilee you want to use the HTTP syringe tool on.

#### Parts to buy

| Description | Quantity per control box | Vendor 1 | Est. total cost | Notes |
| --- |--- | --- | --- | --- |
| Raspberry pi 4 8GB | 1 | [PiShip.us](https://www.pishop.us/product/raspberry-pi-4-model-b-8gb/) | $75 | This is flexible. You may need to change GPIO pin assignments in config if you use a different model. We use an 8GB, you may get away with less but we haven't tested. |
| Power distribution block | 1 | [OONO via Amazon](https://www.amazon.com/OONO-Position-Terminal-Distribution-Module/dp/B08TBXQ7H6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) | $11 | |
| 6V DC power supply | 1 |  [Amazon](https://www.amazon.com/Adapter-5-5x2-1mm-5-5x2-5mm-Compatible-Transformer/dp/B092V8X3BP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) | $11 | You probably have one sitting in your box of cables somewhere |
| Panel mount barrel jack receptacle | 1 | [Amazon](https://www.amazon.com/Threaded-Adapter-Connector-Dustproof-lkelyonewy/dp/B091PS6XQ4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) | $1.5 (Sold in 8 pack) | Any other quick-connect plug for DC power will work here |

### Parts to print

This control support module is designed to fit onto the [Autonomous Formulation Lab](https://pubs.acs.org/doi/full/10.1021/acs.chemmater.2c03118) modular frame system. For use with Jubilee, modifying this box to mount to the back panel of Jubilee would make more sense.

| Part Name | Quantity | Link | Print notes |
| --- | --- |--- |---|
|Control support module | 1 | [module_main v2.stl](https://github.com/machineagency/science-jubilee/blob/main/tool_library/HTTPsyringe/designs/control_box/stl/module_main%20v2.stl) | |
| Lid | 1 | [module_lid v3.stl](https://github.com/machineagency/science-jubilee/blob/main/tool_library/HTTPsyringe/designs/control_box/stl/module_lid%20v3.stl) | |

## Assembly Instructions

Put it together. It should look like the pictures when you are done. Better instructions to come.

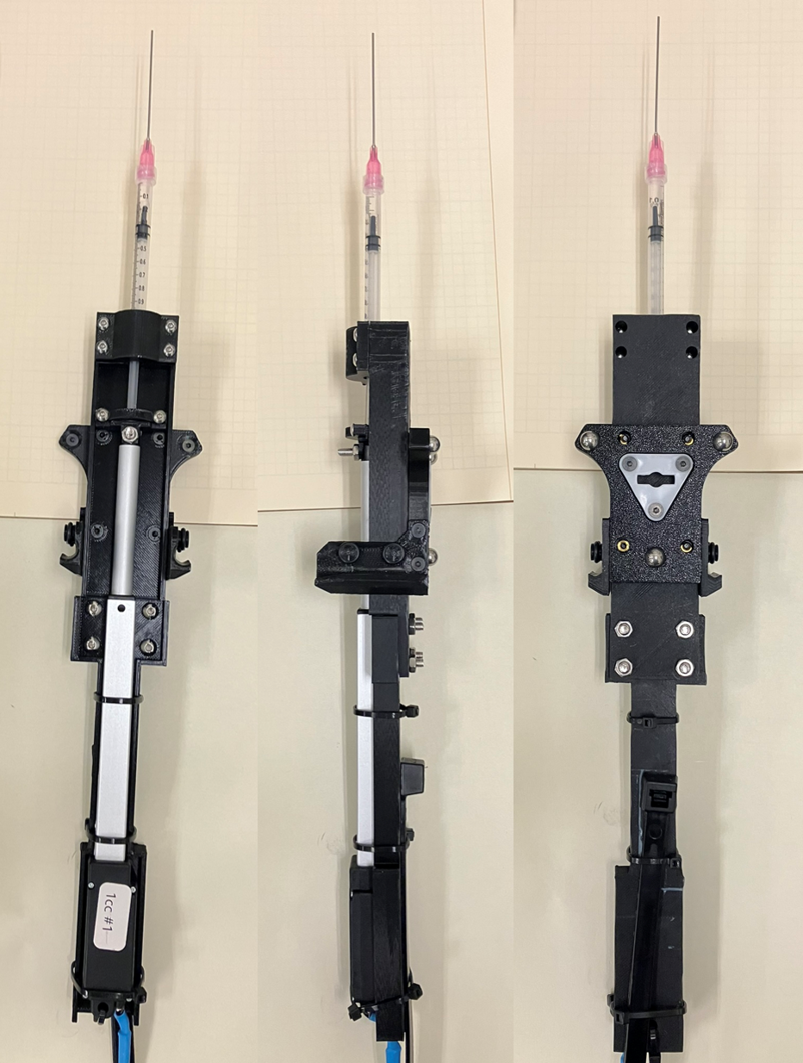
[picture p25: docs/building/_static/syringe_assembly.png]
```{figure} _static/syringe_assembly.png
```

### Wiring

To wire the servo motor, you need to extend the wires it comes with, connect the power wires to a 6V DC power supply, and connect the signal wire to a GPIO pin on a raspberry pi.

1. Extend the servo motor leads to an appropriate length (~6 feet) using the 22g hookup wire, butt splices, and heat shrink. Use the same colored wires to extend them, or note how the extensions connect. Optional but strongly suggested: Place the expandable wiring sleeve over the wires to keep things tidy.
2. Connect the wires to the M12 connector. The DC+ wire (red) should go in pin 1, ground (black) in pin 2, and white (signal) in pin 3.
4. Solder leads onto the M12 panel mount socket. Ideally use the same wire colors as for the servo motor wiring. Match the pins on the socket to the pins on connector. The panel-mount connected signal wires should terminate with female jumper wire connectors to plug into the pi. The easiest way to do this is to sacrifice a pre-wired jumper wire.
5. Install the through-panel connectors into the control module box.
6. Select GPIO pins to use for the syringe control. Note which pin is used for which syringe tool, you will need this to configure the control software later. [Here](https://pinout.xyz/) is one diagram to do this. Note that you want the GPIO pin number, not the pin ordering number. (ie, GPIO23, not pin 16).
6. Wire the inside of the control box as shown in the picture. The power wires for the connector get connected to the power rail, and the signal wires plug into pi GPIO pins. Connect a ground wire between a ground screw on the power rail and a ground pin on the pi. Connect the power rail to the separate 6V power supply, ideally using a through-panel barrel connector.

## Software configuration

The control software for the pipette tools runs as a separate service on the raspberry pi. The science-jubilee http_syringe tool python module that you load in your notebook to control the tool makes requests to this service to aspirate and dispense volumes. The digital_pipette_server manages the positioning of the servo motors to dispense appropriate amounts of liquid. The science-jubilee 'tool' object still manages all the jubilee state, such as positioning the syringe tip in the correct location. Thus, all configuration related to volumetric calibration is done on the raspberry pi, and all tool offset configuration is still done on Jubilee. To configure the http_syringe tool, you need to provision the pi and install the digital_pipette server on it, configure the science-jubilee http_syringe tool to talk to the server, and run a calibration to determine appropriate syringe end limits and calibration constants.

1. Install and configure the [digital_syringe_server](https://github.com/pozzo-research-group/digital_pipette_server) library. The readme of this repository walks you through this process. This should be installed on the raspberry pi used to control the syringes.

The rest of the syringe control and configuration will take place on the computer you use to control your jubilee. This could be but is not necessailly the same raspberry pi used to control the syringes

2. Create local configuration files for your syringe tools in the `science_jubilee/src/science_jubilee/tools/configs` directory. There is an example template there. This configuration contains the URL of the server and the name of the syringe. The name in the config file must match the name you gave your syringe in the server configuration on the raspberry pi.

Example format:

```
{
    "url": "http://192.168.1.5:5000",
    "name": "example_syringe"
}
```
## Installing on Jubilee

You will need to install the tool on Jubilee. This requires [setting parking post positions and tool offsets](https://science-jubilee.readthedocs.io/en/latest/getting_started/new_user_guide.html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).

:::{tip}
If you are using a long syringe needle/tip, a slightly bent or misaligned needle can cause the tool offset at the tip of the tip to be different from the offset at the base of the tip. This can cause issues when using small labware or septa. To mitigate this, you can first set the tool offset of the syringe tool without a tip installed, using the luer-lock fitting of the syringe barrell as the reference point. Then, install the syringe tip and carefully bend the needle until the tip is aligned with your tool offset reference point.
:::

## Using the tool

Stop and double check that you have the following before proceeding:

- A network connection between the computer running science-jubilee and the syrine tool raspberry pi
- The `digital_syringe_server` service up and running on your raspberry pi, with default configurations set
- The syringe tool(s) physically installed on your Jubilee, with parking post positions and tool offsets configured.

1. Bring up a jupyter notebook and connect to your science-jubilee in the usual manner:

    ```from science_jubilee import Machine as Jub
    jubilee = Jub.Machine(address='192.168.1.2')
    ```

2. Import the syringe tool module:

    ```from science_jubilee.tools import HTTPSyringe as syringe```

3. Instantiate a syringe object. Here we will do this from the config file we defined above. The `from_config` method takes two arguments: A Jubilee tool index and the path to the config file.

     ```syringe_tool = syringe.HTTPSyringe.from_config(1, "../../science-jubilee/src/science_jubilee/tools/configs/10cc_syringe.json")```

    If this times out due to a network connection error, then you likely either a) have a network configuration isssue preventing you from connecting to the raspberry pi, or b) have an error with the digital_syringe_server configuration.

4. Load the syringe object onto the science-jubilee machine object in python:
    ```jubilee.load_tool(syringe_tool)```

5. The syringe tool requires another initiation step (also called 'load') before it can move. Because the servo motor doesn't have a homing mechanism, it needs to be told where it is and what liquid amount it is filled with before it can transfer liquids. Due to how this was implemented, this 'load' step also needs to be done before the tool will move at all. For now, we'll use placeholder values of pulsewidth = 1500 and volume = half of total capacity. For a 1cc syringe, the load command is:
```syringe_tool.load_syringe(1500, 500)```

6. Now you can manually move the syringe. This is done by setting the 'pulsewidth' for the servo, as described in the [digital_pipette_server docs](https://github.com/pozzo-research-group/digital_pipette_server?tab=readme-ov-file#implementation-notes). First, set the syringe pulsewidth to 1500:

    ```syringe_tool.set_pulsewidth(1500, s = 200)```

    The first argument is the (integer) pulsewidth value in the range [1000, 2000] to set the pulsewidth to, and the 's' optional parameter is the speed, in uL/s, to move at. Note this command subverts the position and volume tracking that underpins the volumetric aspirate and dispense functions of the tool. Use set_pulewidth sparingly, and re-run the load_syringe procedure after adjusting the syringe with it. Note also that the pulsewidth is an absolute position for ther servo.

When you run this command for the first time, the syringe should move. If it doesn't:
- The syringe may already be at pulsewidth = 1500. Try another value like 1600.
- If you are not getting any errors, check the logs for the `digital_pipette_server` service on the pi. You should see some evidence of the pulswidth for the relevant syringe tool being set. If not, investigate your configurations.
- If the logs indicate a pulsewidth was set, check that 1) the servo signal wire is plugged into the same GPIO pin as is specified in the config file on the raspberry pi for that syringe tool (note again that the GPIO pin number is different from the raspberry pi pin position number), and 2) All wiring to the servo is correct, and the servo is getting power.

Congrats! You have a working syringe tool now.

### Final configuration
Next you need to correctly set the emtpy and full position pulsewidths.
1. Find the 'empty' position pulsewidth by slowing moving the plunger down by increasing the pulsewidth in subsequent calls to the `set_pulsewidth` method. Stop when the plunger is all the way down and record this value. Be careful not to damage the servo, syringe, or frame; move slowly as you approach bottom out.

2. Find the 'full' position by moving the plunger up (by decreasing the pulswidth value) until the plunger is aligned with the maximum capacity marking on the syringe barrel.

3. Update the appropriate config file on the raspberry pi with the correct full and empty positions.
4. Restart the digital_pipette_server server for the changes to take effect.

### Loading the syringe with liquid
The simplest way to load liquid into the syringe tools is:
1. Move the plunger all the way to the empty position:
```syringe_tool.set_pulsewidth(syringe_tool.empty_position - 1)```
2. Place the tip/needle of the syringe in your liquid by holding the liquid container up to the parked syringe.
3. Draw up a syringe full of liquid by moving the syringe to the full position:
```syringe_tool.set_pulsewidth(syringe_tool.full_position + 1)```
Note the -1/+1 modifiers are due to a positioning check that prevents the tool from moving all the way to the full/empty position.
4. Optional: Deadspace in the tip likely resulted in a small volume of air being drawn up. This may be a problem for volatile liquids where headspace evaporation will cause dripping, or for dispensing into sealed vials that become pressurized on fluid injection. This air can be purged by the following procedure. Note that this will eject liquid from the syringe tip. An appropriate containment device such as a septa-sealed vial or absorbent paper towel should be used to contain the liquid. Wear eye protection.

    - Remove the syringe tool from the Jubilee parking post and invert it so the syringe tip points up.
    -  Get all the air bubbles to the top of the syringe near the needle. It may be necessary to knock the side of the syringe tool frame with something solid like a screwdriver to dislodge any bubbles that stick to the sides.
    - Cover the syringe tip with the above described containment mechanism
    - Hold the syringe so your hands are clear of any moving parts
    - Eject a volume greater than the volume of the contained air from the tip of the syringe. Generally moving the syringe by 150 pulsewidth points is sufficient, ie:
```syringe_tool.set_pulsewidth(syringe_tool.full_position + 150)```
This should eject all the air. If any remains, repeat for a larger dispense volume.

    Alternatively, you can manage deadspace by reserving a buffer volume during transfers that is not dispensed. This is not directly implemented currently. To do this you would estimate the deadspace volume typical of a syringe/needle/liquid combination, then always aspirate your target dispense volume + this volume buffer + a little extra when you do a liquid transfer. Then dispense the desired dispense volume into your target location and either return the buffer volume to the stock vial, or dispose of it.

5. Re-load the syringe tool to update the volume and position. Note it is critical you get the current pulsewidth correct here. The volume should be a rounded-down estimate of the volume read off the side of the syringe barrel.
```syringe_tool.load_syringe(current_pulsewidth, current_volume)```

Now you are ready to calibrate your syringe

### Gravimetric calibration

To perform accurate liquid handling, you will need to calibrate the syringe tool using a gravimetric calibration. This is done by dispensing water into a vial using a known pulsewidth, determining the mass and thus volume of the dispensed water, then take an average to determine the conversion factor of pulsewidth change per uL. It is suggested to do at least 5 dispenses at each pulsewidth change in [50, 100, 250, 500]

1. Pre-weigh a sufficient number of vials (And record the weights and keep track of which vial is which)
2. Load your syringe with water
3. For each vial, dispense water by advancing the syringe by the appropriate pulsewidth amount. For example, if you are on the pulsewidth change = 50 step of the calibration and your syringe is currently at pulsewidth = 1230, advance the syringe by 50 points with the command ```syringe_tool.set_pulsewidth(1270)```.
4. After each dispense, weigh the post-dispense vial

[This notebook](https://github.com/machineagency/science-jubilee/blob/document_httpPipette/tool_library/HTTPsyringe/Syringe_calibration_validation_example.ipynb) is set up to run the calibration procedure.

To process the resulting data into a calibration constant:
1. Calcuate the mass of each dispense by subtracting the dry vial weight from the post-dispense weight
2. Convert the mass to a volume using the density of water
3. Calculate a uL per microsecond value for each dispense by dividing the volume delivered by the pulsewidth change
4. Calculate an average uL per uS value for the experiment by averaging all the values from step 3. They should all look similar, if they don't something may be wrong.
5. Invert the uL per uS value to get the uS per uL calibration constant
6. Update the calibration file for the syringe tool on the raspberry pi with the new calibration constant, and reboot the pi.

You now have a calibrated syringe! It is recommended to follow up with a volumetric validation, following the same procedure as above but with volume dispenses instead of pulsewidth steps, to verify the accuracy and precision of your syringe.

### Transferring liquids

To transfer liquids with the Digital Pipette syringe, use the aspirate and dispense methods. These function identically to the aspirate and dispense methods for the OT2 pipette.

To aspirate (pick up) a volume of liquids from a location:
```syringe_tool.aspirate(volume, location)```

And to dispense into a destination:
```syringe_tool.aspirate(volume, location)```

#### License

The original Digital Pipette tool, and this derivative work, are licensed under [CC4.0](https://creativecommons.org/licenses/by/4.0/)

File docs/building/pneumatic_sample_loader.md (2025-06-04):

---
title: Pneumatic Sample Loader
----

(pneumatic-sample-loader)=
# Pneumatic Sample Loader

AFLoverview

The pneumatic sample loader tool adapts the [NIST Autonomous Formulations Laboratory sample loading system](https://www.nist.gov/ncnr/ncnr-facility-upgrades/autonomous-formulation-lab-afl) onto the Jubilee platform. This system adds the capability of transferring liquid samples prepared on the Jubilee platform to a flow cell sample container for measurement, for example with an x-ray scattering instrument. The science-jubilee 'tool' module of this system allows the NIST-AFL system and science-jubilee to co-exist and allows control of the AFL system from the science-jubilee control software. This NIST-AFL system is fully documented at the system's [repository](https://github.com/pozzo-research-group/AFL-sample-loader). See the build guide here for usage instructions.

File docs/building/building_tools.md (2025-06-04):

---
title: Building Science Jubilee Tools
---

(building-science-jubilee-tools)=
# Building Science Jubilee Tools

All tools which are supported in `science-jubilee` are documented here. For existing tools, we link to documentation on the Jubilee project page and provide additional information where necessary. Here, we describe tool prerequisites, the current gallery of tools, how to design a custom tool, and how to calibrate a tool.

(tool-prerequisites)=
## Tool Prerequisites

<!-- Most any Jubilee tool will require a few parts, like a parking post and cable management. If you're new to making Jubilee tools, this page provides some background information.

[Tool Prereqs](tool_prereqs) -->

### Parking Post

Jubilee tools are parked on the rear rail of the machine. To hold the tool when it's not in use, any tool will need a parking post. Several sizes already exist to accommodate tools of varying widths.

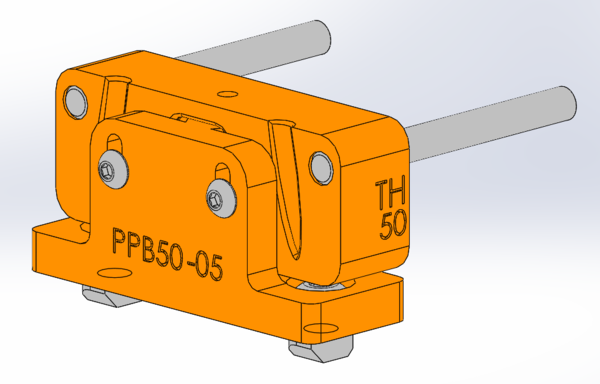
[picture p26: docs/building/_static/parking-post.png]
```{figure} _static/parking-post.png
:scale: 50 %

Diagram of a Jubilee parking post.
```

### Tool Wings

Each tool needs a way to rest on top of the pins of the parking post above. While this is sometimes accomplished in different ways depending on the tool design, a common way is to use tool 'wings', which slide into the parking post pins.

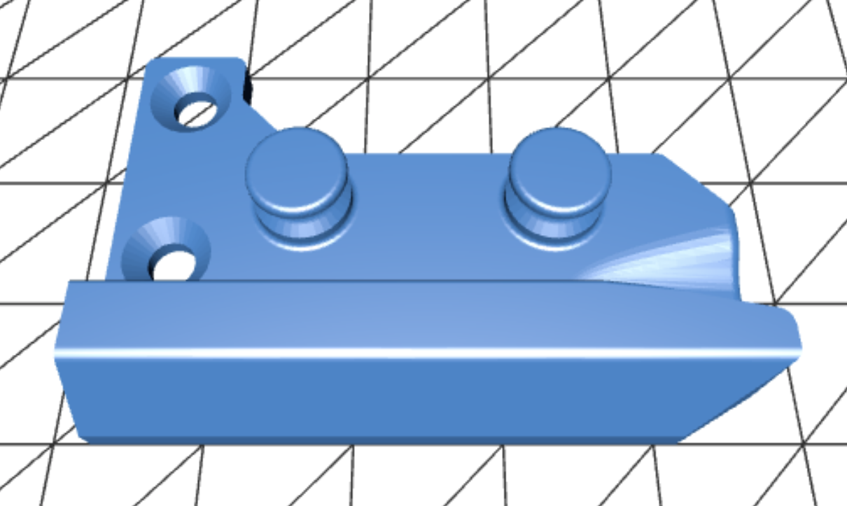
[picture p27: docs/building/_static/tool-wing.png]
```{figure} _static/tool-wing.png
:scale: 20 %

Jubilee tool wing
```

See the video below to get an idea of how the tool wing works:

<iframe width="354.375" height="630"
src="https://www.youtube.com/embed/F8c2MbFglJU?mute=1"
title="First tool loaded"
frameborder="0"
allow="accelerometer; autoplay; clipboard-write; encrypted-media; gyroscope; picture-in-picture; web-share"
allowfullscreen></iframe>

### Tool Plate

Each tool has a tool plate which couples with Jubilee's toolchanger to be able to be picked up. This tool plate can be 3D printed + laser cut, or you can purchase aluminum toolplates (e.g., [Luke's Laboratory fully assembled tool plate](https://lukeslabonline.com/products/jubilee-tool-plate?variant=41427956859065)).

```{figure} _static/tools.png
:scale: 15 %

Shown are a set of tools parked on a Jubilee; seen on the side of each tool frame are a set of tool wings resting on an accompanying parking post. The tool plates of each tool are visible; note the three threaded steel balls on each which will couple with toolchanger on pickup, and the white wedge plate (made of delrin) in the center.
```

### Fabricating a Tool

To fabricate any tool, you'll need access to:

- a 3D printer, to print parking posts, tool wings, and tool frames;
- a soldering iron, for heat-press inserts;
- a set of hex keys, to tighten up screws.

If you plan on making new tools regularly, it might also be useful to stock up on the following materials:

- Jubilee wedge plates, which can be purchased [here](https://www.filastruder.com/products/wedge-plate-for-jubilee?_pos=1&_sid=b2191c16a&_ss=r);
- M3 & M5 screws;
- M3 heat set inserts;
- O-rings (for use on the tool wings);
- Metal pins (for the parking post).

### Cable Management

Many tools have wires that control tool components like motors and cameras. To keep wires out of the way, you can use [large zip ties](https://www.amazon.com/Gardner-Bender-45-536UVBSP-Heavy-Duty-Electrical/dp/B000BOKN0C) which extend from the Jubilee electronics panel to the tool itself, and zip tie the cables to the large zip tie to hold the wires out of the way. There is also a 3D printable [cable management bracket](https://github.com/machineagency/jubilee/blob/main/tools/jubilee_tools/tools/extruders/direct_drive_bondtech_groovemount_extruder/fabrication_exports/tool_cable_mana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) which can be attached to the back of the rear Jubilee rail to hold cables.

## Tool Gallery

### Pipette Tool

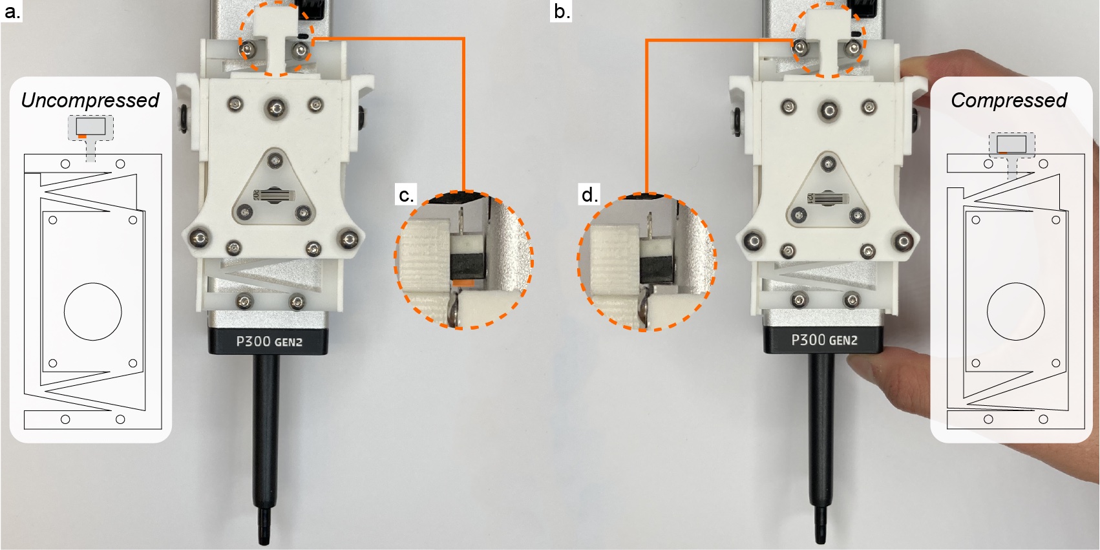
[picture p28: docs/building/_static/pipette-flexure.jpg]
Pipette


To use an OpenTrons Pipette with Jubilee

[Pipette Tool](pipette_tool)

### Inoculation Loop Tool

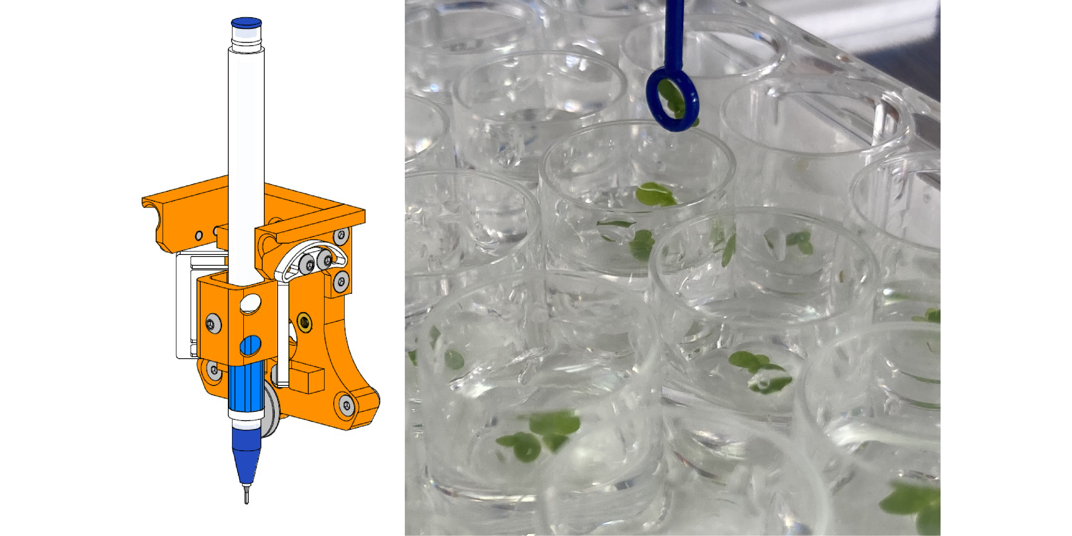
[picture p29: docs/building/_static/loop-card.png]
Inoculation Loop


To hold inoculation loops, pens, or other probes.

[Inoculation Loop Tool](inoculation_tool)

### Top-Down Camera Tool

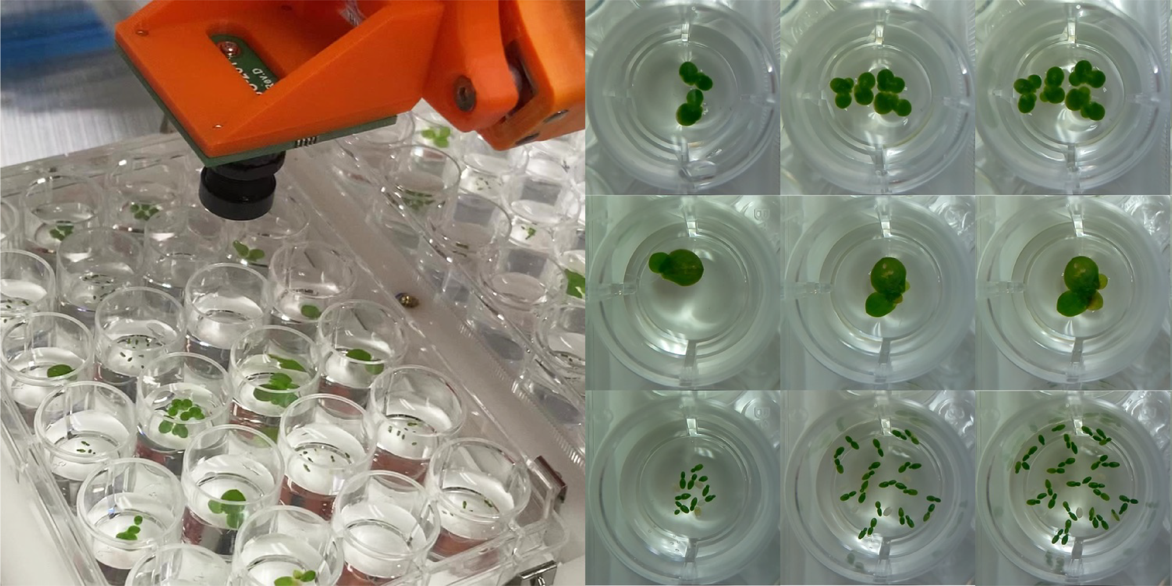
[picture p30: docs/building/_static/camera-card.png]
Top-Down Camera


To hold a Raspberry Pi camera for imaging the deck.

[Camera Tool](top_down_camera_tool)

### Side Camera Tool

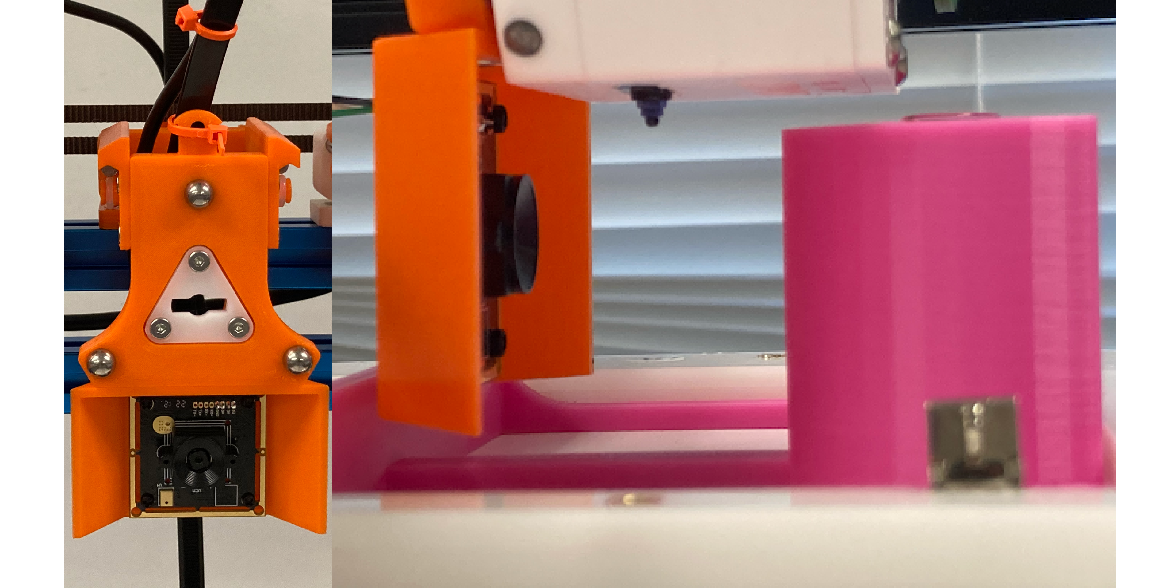
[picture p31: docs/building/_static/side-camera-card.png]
Side Camera


To hold a Raspberry Pi camera to image parallel to the deck.

[Side Camera Tool](side_camera_tool)

### Syringe Tool

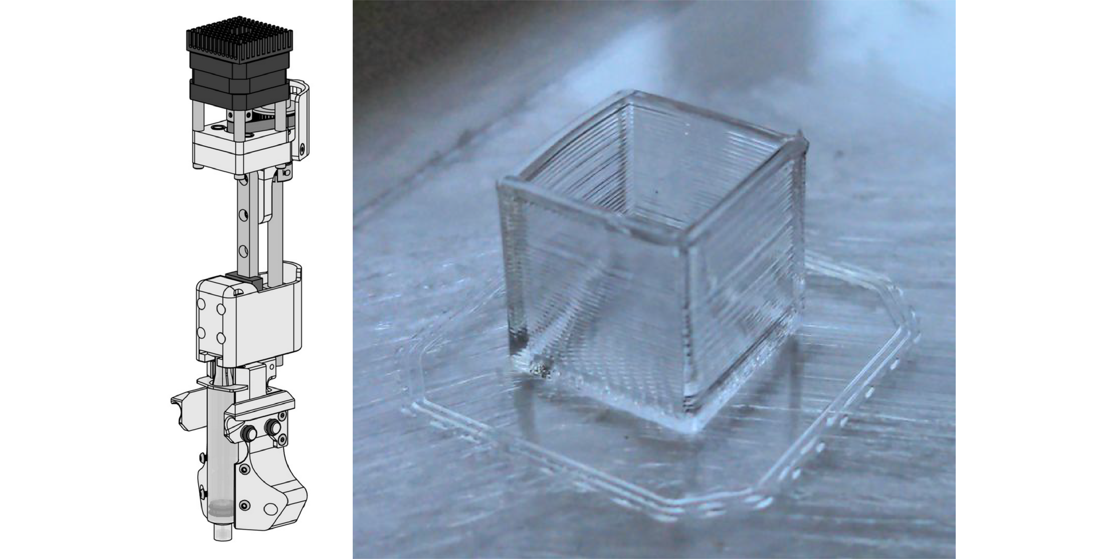
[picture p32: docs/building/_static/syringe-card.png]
Syringe


To hold a 10cc or 50cc syringe.

[Syringe Tool](syringe_tool)

### Lab Automation Deck

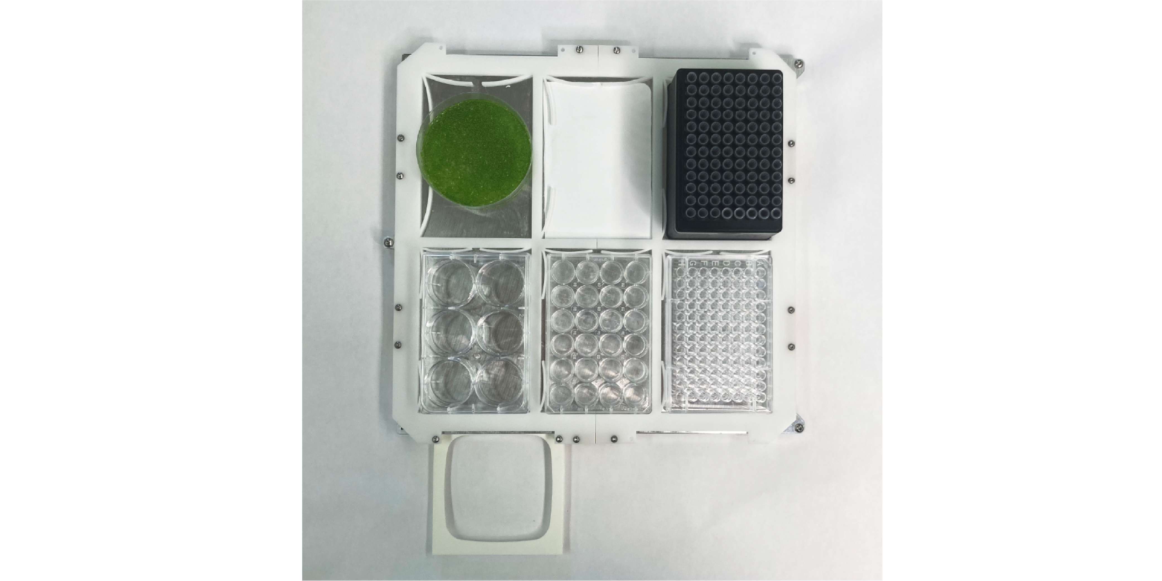
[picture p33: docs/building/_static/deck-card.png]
Lab Automation Deck


Deck attachment to hold 6 standard microplates + disposal containers.

[Lab Automation Deck](lab_automation_deck)

## Designing Custom Tools

The shortcut to 3D modeling a tool with the right placements is to simply build on top of the CAD files in [the template folder](https://github.com/machineagency/jubilee/tree/main/tools/jubilee_tools/tool_template).

```{figure} _static/tool-template.png
:scale: 50 %

Tool template showing dimensions of wedge plate and tool balls (left), an assembled tool plate with tool wings (middle), and a complete USB microscope tool (right).
```
Starting from scratch is also straightforward. To create a custom tool that locks into Jubilee's carriage, you must place the tool balls and the wedge plate in a specific location, specified in the [Tool Template Reference Dimensions](https://github.com/machineagency/jubilee/raw/main/tools/jubilee_tools/tool_template/references/tool_template_reference_dimensions.pdf), copied below.

```{figure} _static/tool-template-reference-dims.png
:scale: 30 %

[Tool Template Reference Dimensions](https://github.com/machineagency/jubilee/raw/main/tools/jubilee_tools/tool_template/references/tool_template_reference_dimensions.pdf)
```

There are a few size constraints that may influence your tool's shape (see below). A number of example tools are shown in the [Tool Interface Diagram PDF](https://github.com/machineagency/jubilee/raw/main/frame/references/tool_interface_diagram.pdf). Note that many of these constraints are soft. Using longer dowel pins on the parking post will allow for deeper tools. Also, moving the tool's active center past the leftmost line will result in a working tool that simply has a bit less Y-axis travel.

```{figure} _static/tool-interference-diagram.png
:scale: 50 %

Tool interference and constraints diagram
```

## Tool Postrequisites

Once you've built a tool, it needs to be calibrated for use on the machine. See here for guides and help on the tool calibration process.

[Tool Postreqs](tool_postreqs)

```{toctree}
:hidden:

pipette_tool
inoculation_tool
top_down_camera_tool
side_camera_tool
syringe_tool
http_syringe
lab_automation_deck
pneumatic_sample_loader
designing_custom_tools
tool_postreqs
```

## Additional Resources

- [https://jubilee3d.com Tool info](https://jubilee3d.com/index.php?title=Tools)
- [https://jubilee3d.com Parking Post info](https://jubilee3d.com/index.php?title=Parking_Post)

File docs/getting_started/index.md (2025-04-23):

---
title: Getting Started with Science Jubilee
---

(getting-started)=
# Getting Started

## Installation

```{eval-rst}
.. card:: Installation
    :class-card: intro-card
    :shadow: md

    Instructions for installing ``science_jubilee``, including integration with Jupyter notebooks.

    +++

    .. button-ref:: installation
        :ref-type: ref
        :click-parent:
        :color: secondary
        :expand:

        Installation Guide
```

## Overview

`science_jubilee` provides a Python interface to operate a Jubilee. It is comprised of:
- a `Machine`, which controls the Jubilee motion platform;
- `tools`, which provide task-specific functionality;
- `decks`, which can be attached to the Jubilee bed plate;
- and `labware` to be used on the machine.

These tutorials focus on applications using a Lab Automation deck which holds 6 standard sized microplates, thus allowing Jubilee to navigate between labware wells. However, there is no requirement to use the Lab Automation deck, and you might find it useful to develop alternative decks for your application!

```{eval-rst}
.. grid:: 1 2 2 2
    :gutter: 4
    :padding: 2 2 0 0
    :class-container: sd-text-center

    .. grid-item-card:: ``science_jubilee`` Primer
        :class-card: intro-card
        :shadow: md

        An introduction to key concepts, including: G-Code, coordinate systems, and an overview of the ``science_jubilee`` Python modules.

        +++

        .. button-ref:: primer
            :ref-type: ref
            :click-parent:
            :color: secondary
            :expand:

            Primer

    .. grid-item-card:: New User Guide
        :class-card: intro-card
        :shadow: md

        A complete start-to-finish walkthrough on running an experiment on Jubilee, starting with purchasing a machine.

        +++

        .. button-ref:: new-user-guide
            :ref-type: ref
            :click-parent:
            :color: secondary
            :expand:

            New User Guide

    .. grid-item-card:: Intro to the Machine Driver
        :class-card: intro-card
        :shadow: md

        Control the Jubilee motion platform and pickup tools using ``science_jubilee``

        +++

        .. button-ref:: machine-intro
            :ref-type: ref
            :click-parent:
            :color: secondary
            :expand:

            Machine Tutorial

    .. grid-item-card:: Lab Automation Deck and Labware
        :class-card: intro-card
        :shadow: md

        Set up a lab automation deck and navigate wells using standard labware.

        +++

        .. button-ref:: deck-guide
            :ref-type: ref
            :click-parent:
            :color: secondary
            :expand:

            Lab Automation Deck Tutorial

    .. grid-item-card::  Pipetting Intro
        :class-card: intro-card
        :shadow: md

        Use the lab automation deck and the pipette tool to run a serial dilution.

        +++

        .. button-ref:: pipette-guide
            :ref-type: ref
            :click-parent:
            :color: secondary
            :expand:

            Serial Dilution Pipetting Tutorial

    .. grid-item-card::  Color Mixing Demo Guide
        :class-card: intro-card
        :shadow: md

        Run an autonomous optimization experiment on Jubilee.

        +++

        .. button-ref:: color-mixing-setup
            :ref-type: ref
            :click-parent:
            :color: secondary
            :expand:

            Color Mixing Demo Guide
```

## Notebooks
You can use the following notebooks to get started quickly. You can find these notebooks in the `docs/notebooks` folder of science-jubilee to run them on your machine.

- [Machine Jogging](../notebooks/MachineJogging.ipynb)
- [Taking Pictures with a Camera Tool](../notebooks/TakingPictures.ipynb)
- [Automation Deck Intro](../notebooks/AutomationDeckIntro.ipynb)
- [Labware Intro](../notebooks/LabwareIntro.ipynb)
- [Setting Z Offsets for Gel Printing](../notebooks/SetZOffset.ipynb)
- [Gel Printing Info](../notebooks/GelPrinting.ipynb)
- [Extrusion Printing with a Syringe](../notebooks/SyringeExtruderIntro.ipynb)
- [Pipette Intro](../notebooks/PipetteIntro.ipynb)
- [Serial Dilution Example](../notebooks/SerialDilution.ipynb)

```{toctree}
:hidden:
installation
primer
new_user_guide
machine_intro
deck_guide
pipette_guide
color_mixing_setup
```

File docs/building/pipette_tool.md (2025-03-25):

---
title: Pipette Tool
---

(pipette-tool)=
# Pipette Tool

The pipette tool mounts an [Opentrons OT2 pipette](https://opentrons.com/products/single-channel-electronic-pipette-p20) to Jubilee to perform liquid handling with disposable pipette tips. Opentrons OT2 pipettes are available in three volume ranges (up to 20 uL, up to 300 uL, and up to 1000 uL) and have a form factor that is amenable to integrating with Jubilee. Many automation-focused labs already have an OT2 and hence OT2 pipettes. This tool provides a way to repurpose them on Jubilee. Compared to syringe-based liquid handling tools, these pipettes avoid the possibility of sample cross contamination and provides options for greater accuracy and precision at low transfer volumes. The tool consists of a mounting bracket to attach the pipette to a tool changer plate, a flexure mechanism that enables pipette tip pickups, and a wiring harness to control the pipette's internal motor. We have been able to reproduce the accuracy and precision values [published by Opentrons](https://opentrons.com.cn/wp-content/uploads/2023/11/Opentrons-Pipettes-White-Paper.pdf) for their pipettes after performing a gravimetric calibration. Choose the OT2 pipette tool if you need disposable pipette tips for your workflow or you need the pipette's accuracy at low volumes. Consider other liquid handling tools if the cost of the pipette is prohibitive, you need access to a wider range of volumes, or you are purchasing pipettes from scratch. While this is an effective pipette tool, due to the high cost and limited feature set of OT2 pipettes we don't recommend that new users purchase them specifically for working with Jubilee. New users should consider a syringe based tool as a starting point. If you do need a true disposable tip pipette, the [Open Lab Automata project](https://www.openlabautomata.xyz/) is developing an open hardware option - keep an eye on them for progress updates. We also are considering alternative commercial solutions and are happy to discuss these more if they are of interest to you.

:::{danger}
Using an OT2 pipette on Jubilee is obviously outside the design and support scope of Opentrons, so do so at your own risk. The Jubilee project further does not guarantee the safety or reliability of the OT2 piptte tool adaptation (or any other component of the Jubilee platform). There is a risk of destroying a pipette with an incorrectly configured machine (ask me how I know this...) so move slow and verify everything is set up correctly.
:::

```{figure} _static/pipette-flexure.jpg
:scale: 50 %

Back of the pipette tool showing the flexure mechanism. When the pipette experiences resistance (i.e., pressing it against a pipette tip to pick it up), the flexure mechanism compresses until an endstop is triggered.
```

```{figure} _static/pickup.gif
:scale: 40 %

Pipette tool picking up a tip. When the flexure mechanism shown above reaches the endstop, the pipette tool considers the tip to have been picked up and resumes other tasks.
```
## Tool versions

There are two versions of the Jubilee pipette tool. One uses a flexure that is laser cut from Delrin. The other uses a 3D printed flexure mechanism. The laser-cut Delrin flexure can be purchased from SendCutSend for around $10 USD. It is cleaner and simpler to assemble, so we recommend using this version. If you can't procure or fabricate the laser cut flexure piece, the 3D printed version works great too!

## Skills and capabilities needed

- 3D printing
- Soldering

## Parts to Buy

- OT-2 Pipette (tested with gen1 and gen2)
- Tipracks for your OT2 pipette
- See the shopping list for tool parts [here](https://docs.google.com/spreadsheets/d/1Bp4ZdpHsX01EHIsc5mqbzi92CpQlax4KNS-QtPmUZUM/edit#gid=1582949094).
    - Corrections:
          - Add 10-pin ribbon cable: 28AWG, 10 conductor ribbon cable, 7.5 feet, digikey option: https://www.digikey.com/en/products/detail/assmann-wsw-components/AWG28-10-G-1-300/21997415
          - Add FC-10P connector for ribbon cable, one option: https://www.amazon.com/Antrader-FC-10P-2-54mm-Connector-50-Pack/dp/B07DVZBQ67?th=1
          - Add 1/2in cable sleeve: https://www.amazon.com/Keco-100ft-Expandable-Braided-Sleeving/dp/B07K1XJNJN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
          - Add 22g hookup wire, something like 40 ft of it
          - Specify separate limit switch for 3D printed flexure version
          - add duet board connector housings

## Parts to Fabricate

- Pipette tool frame SolidWorks file and correctly sized parking posts can be found [here](https://github.com/machineagency/science-jubilee/tree/main/tool_library/OT2_pipette).

## Assembly Instructions

### Wiring Harness Assembly

You will want your wiring harness to be long enough to provide sufficient slack for tool movement when routed down the front of the jubilee, below the machine, and to the back panel. 8 feet of wire length should allow for this.

1. Solder your limit switch to sufficiently long lengths of hookup wire
2. Cut a 7.5 foot length of 10 conductor ribbon cable
3. Attach an FC-10 connector to one end of the ribbon cable so that the 'notch' on the connector is to the left and the red cable insulation is towards to bottom when viewed from above. Attach the connector by pressing down on the housing so the teeth bite into the insulation, using pliers as necessary.
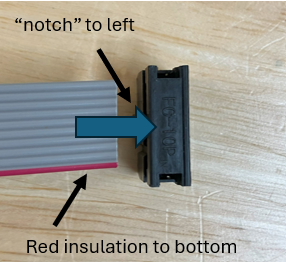
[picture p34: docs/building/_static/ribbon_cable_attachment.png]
```{figure} _static/ribbon_cable_attachment.png
:scale: 100 %
```
4. Cut a length of PET cable sleeve that is about 6 inches shorter than your wires. Use a hot knife to cut this if you have one, or use scissors then melt the edges with a lighter or other heat source to minimize fraying.
5. Run your ribbon cable and limit switch wires through the cable sleeve. Make sure the limit switch and FC-10P connector are on the same side of the cable. Cover the ends of the PET housing with heat shrink tubing.

:::{tip}
Use electrical tape to tape the loose ends of the wires together to make routing them through the sleeve easier, then use a pinching motion to feed the wires through
:::

6. Add 22 awg extensions to the free end of the ribbon cable. This is necessary to allow attachment of connector crimps. The following instructions assume you are using blue, red, green and black hookup wire. You can use whatever color wire you have/want but do make sure to keep track of the order. Make these attachements by soldering and cover each connection with a piece of heat shrink.

| Ribbon cable position | Hook-up wire |
| --- | --- |
| 10 | None |
| 9 | None |
| 8 | None |
| 7 | Red - limit switch |
| 6 | Black - limit switch |
| 5 | None |
| 4 | Blue - stepper motor |
| 3 | Red  - stepper motor |
| 2 | Black - stepper motor |
| 1 (red insulation) | Green - stepper motor |

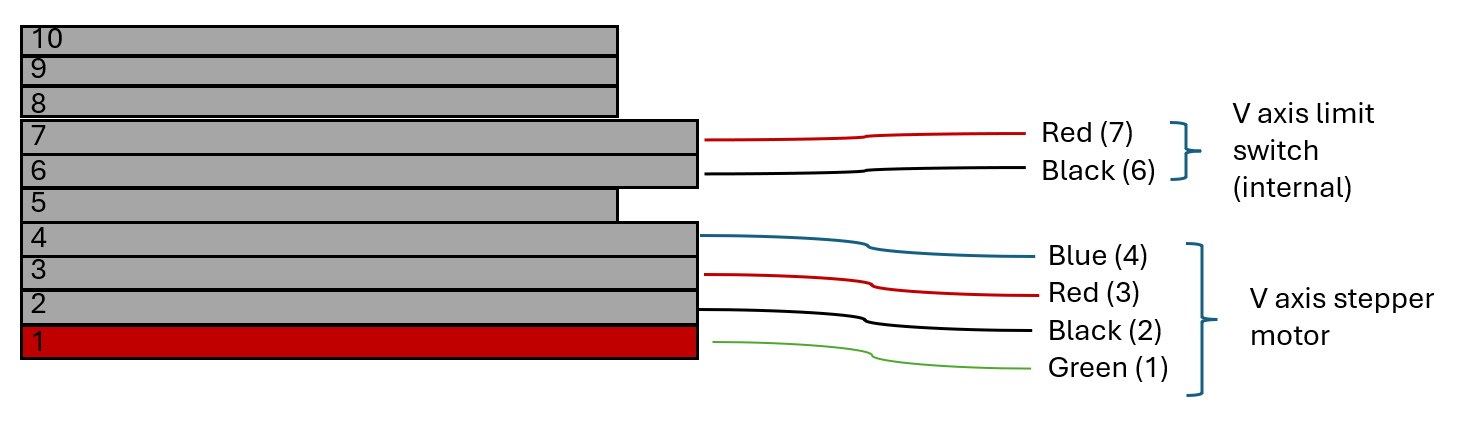
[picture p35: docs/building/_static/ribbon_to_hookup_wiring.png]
```{figure} _static/ribbon_to_hookup_wiring.png
:scale: 75 %
```
6. Terminate the 4 stepper motor hookup wires with appropriate crimps for the driver you will be using. If you are attaching the stepper motor to a driver on a duet expansion board as the rest of the instructions will do, use a VH crimp. See [prerequisite knowledge](prerequisite_knowledge.md) for more on this.
7. Terminate the 4 limit switch wires (2 for the external limit switch and two for the internal limit switch) with molex KK254 connectors.
8. Place the terminated stepper motor wires in a JST VH 4 pin housing. When viewed from the contact side of the connector with the wires entering from the left, the order from top to bottom should be (in terms of color/ribbon cable position): [Blue/4, Red/3, Green/1, Black/2].

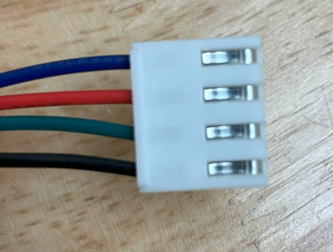
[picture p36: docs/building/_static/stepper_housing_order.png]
```{figure} _static/stepper_housing_order.png
:scale: 75 %
```

9. Place the terminated limit switch wires into a molex 5-pin housing, in positions 2 and 3.

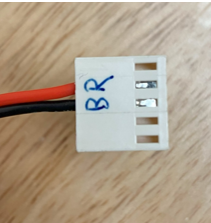
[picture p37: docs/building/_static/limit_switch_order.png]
```{figure} _static/limit_switch_order.png
:scale: 75 %
```

### Mechanical Assembly
Follow the version of the assembly instructions for the flexure design you chose:

- [Version using only 3D printed parts](https://github.com/machineagency/science-jubilee/blob/main/tool_library/OT2_pipette/assembly_docs/OT2_Pipette_3D_only_assembly_instructions.pdf)
- [Version using 3D printed parts and a laser-cut flexible delrin part](https://github.com/machineagency/science-jubilee/blob/main/tool_library/OT2_pipette/assembly_docs/OT_laser_cut_assembly_instructions.pdf)

### Wiring Connections

The following Duet configuration guidelines will assume that you wire your new pipette tool to your Jubilee as follows

| Connector | Duet board position |
| --- | --- |
| Stepper motor | Driver 2 on expansion board 1 |
| External (pipette tip pickup) limit switch | IO2 on board 0 |
| Internal (V axis) limit switch | IO3 on board 0 |

See the [default wiring instructions](wiring.md) for illustrations.

## Duet Configuration
These lines should be added to the `config.g` on *your* machine.

> Note:
> 1. Anywhere you see `<>`, you should remove the greater than/less than signs and replace them with the correct information based on *your* machine.
> 2. Be careful where you add the g-code lines in your `config.g` file as the order in which they are defined matters! You'll find information on where to add each one below.
>
>For more information about G-code, see the  [Duet G-code Documentation](https://docs.duet3d.com/en/User_manual/Reference/Gcodes) or the [RepRap G-code Wiki](https://reprap.org/wiki/G-code).
___
### 1. Set Drive Mapping

    M584 V<your_drive_number>

This command defines a new axis for the pipette motor and tells the Duet which board driver number you're using.
We use the *V* axis here; however, if it is already in use on your machine, you can also use *W/A/B/C*. Each driver on the Duet boards are labeled (e.g., `driver_0`,`driver_1`, etc.). Add the driver number (`n`) here and preped it with `1.n` if you are using an expansion board.

This G-code line shuold be placed the `M584` commands for your other axes in your `config.g` file. It has to come before all the other `M codes` we’ll add next.

> **Example**:
>
>     `M584 V1.2` ; pipette plugged into driver 2 on the expansion board
>     `M584 V0`   ; pipette plugged into driver 0 on the main board

### 2. Set Stepper Direction

    M569 P<your_drive_number> S0

This command sets the stepper motor direction. The `P` field should match the M584 command above. The `S` field can be either 0 or 1.
Add this command alongside the `M569` commands for your other motors in your configuration file.

:::{warning}
The **first time** you home the pipette, you should check the direction that the motor is moving by removing the front plate and watching the draft shaft move.
During a homing step, it shold move towards the *endstop*. If it is moviong in the wrong direction (i.e., downwards), **manually** engage the endstop (i.e., click it!) and change the `S` parameter on this line from 0 to 1. Try again and make sure the motor moves in the expected direction.
:::

> **Example**:
>
>     `M569 P1.2 S0 `

### 3. Set Motor Current

    M906 V<peak_current_in_milliamps>

This commands sets the peak motor current.
* For *Gen1* pipettes this shuold be **350** mA
* For *Gen2* pipettes this should be **500** mA
Add this command alongside the othe `M906` for the other moto5rs defined in your configuration file.

> **Example**:
>
>     `M906 V350` ; 350mA peak current for gen1 pipette
>     `M906 V500` ; 500mA peak current for gen2 pipette

### 4. Set Steps Per Millimeter and Step Type

    M92 V<steps_per_mm>
    M350 V16 I1

Set the number of steps/mm and enables *16x* microstepping with interpolation.
* For *Gen1* pipettes this should be **48**
* For *Gen2* Pipettes this should be **200**
Add these commands alongside the other `M92` and `M350` commands in your `config.g` file.

> **Example**:
>
>     `M92 V48`    ; for a gen1 single channel pipette
>     `M92 V200`   ; for a gen2 single channel pipette
>     `M350 V16 I1` ; set microstepping after M92 command
>
> Note: do not disable microstepping prior to define the `M92` command for the pipette motor to simplify calculations as it will mess with the motor settings (not sure why)

### 5. Set V Axis Motion Attribute Limits
    M201 V800
    M203 V10000
    M566 V4000

These commands set the max acceleration (`M201`), speed (`M203`) and jerk (`M566``) for the V axis.
Add these command alongside the M201/203/566 commands in your configuration file.

### 6. Configure Endstop

    M574 V1 S1 P"^<your_pin_name>"

This command configures the endstop for the **internal** axis limit switch. Note that the carat ("^") should be included to enable the pullup resistor; the quotes (" ") are necessary.
Pins are named as `<board_index>.<pin>.in`. The *pin* number can be found on your Duet board.
Add this command alongside the other `M574` commands.

> **Example** :
>
>     `M574 V1 S1 P"^0.io3.in"` ; pipette endstop plugged into io3 on main board

### 7. Define Tool
    M563 P<tool_number> S”<tool_name>”

This command actually defines your tool. The tool number should be set based on the other tools you already have defined, and you can name your tool whatever human-readable text you’d like to see it as in Duet Web Control. Note that, because we are using the *V axis*, we do not need to add a `D` field here (as we might for a syringe or extruder tool).

> **Example**:
>
>     `M563 P1 SP300 Pipette”` ; pipette with tool index 1

### 8. Define Pipette Tip Endstop

    M574 Z1 P"^<your_pin_name>"

This command is to define the external endstop for picking up pipette tips.
In this case,  it will be an enstop for the *Z axis* instead of the pipette axis (*V*). Similarly to section 6, the carat ("^")and the quotes (" ") are necessary in thsi line as well.
Again, pins are named as follows `<board_index>.<pin>.in`.
Add this command alongside the other `M574` commands

> **Example**:
>
>     `M574 Z1 P"^0.io2.in` ; pipette top pick up endstop plugged into io2 on main board

### 9. Define Homing Macro
You are now done with updating your `config.g` file!
 Next, you'll need to define the homing routing for the pipette. In the *Duet Web Control*, navigate to *System* (i.e., *sys/*), then add a *New File* and name it `homev.g`.
 Add the following content to it:

    G91              ; relative moves
    G1 V-200 F800 H1 ; big, slow negative move to look for endstop
    G1 V1 F600       ; back off endstop
    G1 V-10 F600 H1  ; find endstop again, slower
    G90              ; absolute moves
    G1 V0.5 F600     ; move to a position of 0.5 to start

**Remember**: The *first time* you home the pipette, you should check the direction of the mototr movement and ensure the draft shaft is moving upwards towardsthe endstop. If you notice the pipette tip ejector starts to engage, then manually stop the motion by pressing the endstop twice (to account for both searches for the endstop in the homing routine), and flip the direction of the motor (see step 2.)

### 10. Add V Homing to `homeall.g`

The `homeall.g` macro is used to home each of the machine's configured axis at once. You can call the `homev.g` macro at the end of this file, and the pipette will home while sitting in its parking position.To do so, navigate to *System* (i.e., *sys/*), open `homeall.g`, and add the following line to the end:

    M98 P"homev.g"

You are now done and your pipette should be configured!

## Parking post positions and offsets
Now you are ready to power on the machine and complete the tool setup procedures.

:::{warning}
The **first time** you home the pipette, you must check the direction that the motor is moving by removing the front plate and watching the draft shaft move. This will happen when you home all axes on the machine, so now is the time to check this. To do this, remove the two torx screws from the top of the pipette, slide the black plastic piece up about 1/2 inch, then pull the plastic off to the front. Nothing should need to be forced to remove the front cover.
During a homing step, it shold move towards the *endstop*. If it is moviong in the wrong direction (i.e., downwards), **manually** engage the endstop (i.e., click it!) and change the `S` parameter on this line from 0 to 1. Try again and make sure the motor moves in the expected direction.
:::

Set the [parking post positions](parking_posts.md) and [tool offset](tool_offsets.md) as described elsewhere in the documentation.

## Using the pipette tool

:::{danger}
The first time you use your new pipette tool, you should test the pipette tip pickup limit switch functionality. The pipette tool relies on the triggering of an endstop to detect a pipette tip pickup and stop bed movement. An incorrectly wired or configured endstop can lead to the bed continuing to move upwards after the pipette and tip rack have made contact, potentially destroying your pipette. Test this functionality by dropping the bed substantially in z, then having the pipette move to pickup a tip. While the bed is moving up, grab the pipette and pull it up. The endstop should trigger, stopping the bed and registering a tip pickup. If the bed keeps moving, cut the power and investigate.
:::

Link to pipette usage example notebook:

To use a pipette in the science-jubilee python interface, start by setting up your Jubilee and loading labware as in the getting started notebook.

Next, import the pipette tool module:

```python
from science_jubilee.tools import Pipette
```
Define and load the pipette tool:

```python
P300 = Pipette.Pipette.from_config(0, 'Pipette', 'P300_config.json')
jubilee.load_tool(P300)
```

Add a tiprack and trash location (already loaded as labware)

```python
P300.add_tiprack(tiprack)
P300.trash = trash[0]
```

Pickup the tool
```python
jubilee.pickup_tool(P300)
```

Use one of the pipette commands to handle liquid. Depending on the command, tip management will be handled automatically.

```python
volume = 50 # uL
source_location = stock_solutions['A1']
well_location = samples['A1']
pipette.transfer(volume,
                 source_location,
                 well_location,
                 blowout = True,
                 new_tip='once')
```

See the [pipette API documentation](https://science-jubilee.readthedocs.io/en/latest/autoapi/science_jubilee/tools/Pipette/index.html) for more details

## Media

<iframe width="708.75" height="398.25" src="https://www.youtube.com/embed/meaXhH14zzY?si=4p9Iwl6hgjO9En3n" title="Assembling the 3D printed only version of the OT2 pipette" frameborder="0" allow="accelerometer; autoplay; clipboard-write; encrypted-media; gyroscope; picture-in-picture; web-share" referrerpolicy="strict-origin-when-cross-origin" allowfullscreen></iframe>

<iframe width="354.375" height="630"
src="https://www.youtube.com/embed/pMmDV9pAfZU"
title="Assembling tool post"
frameborder="0"
allow="accelerometer; autoplay; clipboard-write; encrypted-media; gyroscope; picture-in-picture; web-share"
allowfullscreen></iframe>

<iframe width="354.375" height="630"
src="https://www.youtube.com/embed/0mGqOwAkS5k"
title="Arbor press"
frameborder="0"
allow="accelerometer; autoplay; clipboard-write; encrypted-media; gyroscope; picture-in-picture; web-share"
allowfullscreen></iframe>

<iframe width="354.375" height="630"
src="https://www.youtube.com/embed/F8c2MbFglJU?mute=1"
title="First tool loaded"
frameborder="0"
allow="accelerometer; autoplay; clipboard-write; encrypted-media; gyroscope; picture-in-picture; web-share"
allowfullscreen></iframe>

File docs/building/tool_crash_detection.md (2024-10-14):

---
title: Crash Detection
---

(crash - detection)=
# Science Jubilee Tool Crash Detection

A Jubilee crash is an unwanted collision between the current tool or toolchanger carriage and the bed plate or labware on the deck. You will (almost certainly) crash your Jubilee. This can happen when you click the wrong button in the duet web control interface while aligning samples, forget to remove labware from the deck before homing or improperly align your labware, to name a few examples. Depending on the context in which it occurs, a crash can range from a minor annoyance requiring a machine re-start, through an expensive mistake causing thousands of dollars of damage, up to a serious safety incident involving spilled chemicals or crush injuries. When using Jubilee in a scientific setting, crash detection is highly desireable. We see three theoretically possible options for detecting crashes: 1) tool ball contact sensor trigger, 2) stepper motor stall guard, and 3) computer vision based incident detection. We have implemented  option 1 and reccomend new Jubile users do as as well. The other two are described here for completeness, but we have not gotten them working.

## Tool ball contact sensor crash detection

```{youtube} IgjtlrmePy0
```

This approach uses the contact between the tool balls and the kinematic coupling pins as a switch. The idea is that meaningful force applied to the tool will twist at least one of the tool balls out of it's seat with the tool changer pins. This will break the circuit and trip a trigger set up in the Duet firmware. We are in the early phases of testing this solution. So far, it provides reliable crash detection for collisions in the X, Y, and Z directions. There is a possibility for false positives, which seems to be reduced by increasing the torque on the tool changer locking pin. Implementing this requires electrically connecting the toolchanger interface dowel pins and modifying your machine configuration. We have not tested this implementation with the pipette tool or other tools that need to exert force on the deck to operate.

### Implementing tool ball contact sensor

```{warning}
This feature is in early development. You may run into unexpected issues.
```

#### Parts required:
1. Jubilee [carriage coupler plate ](https://github.com/machineagency/jubilee/blob/main/frame/fabrication_exports/3d_printed_parts/toolchanger/toolchange_carriage/carriage_coupler_plate.STL) printed part. Follow the main [Jubilee printing instructions.](https://jubilee3d.com/index.php?title=3D_Printed_Parts#Default_Print_Settings)
2. Threaded dowel pins, M3x4mmx20mm. You need 6 of these per Jubilee We use [these ones](https://www.aliexpress.us/item/3256805293246699.html).
3. M3x4mm buttonhead screws, quantity 6
4. [M3 solder lug](https://www.digikey.com/en/products/detail/keystone-electronics/7328/316697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), quantity 6. These are the same part used in the toolchanger REL mechanism so you might have some spares.
5. Hookup wire, 22 or 24 gauge
6. Contacts and housing for 5-pin molex connector (for Duet IO ports)

#### Tools required:
1. Arbor press or other means of inserting dowel pins
2. [Tool carriage pin insertion fixture](https://github.com/machineagency/jubilee/blob/main/tools/assembly_fixtures/coupling_plate_pin_insertion_fixture.STL) (print)
3. Soldering station (soldering iron, solder, etc)
4. Wire crimping tool (ex [Engineer PA-09](https://www.amazon.com/ENGINEER-AWG32-AWG20-Connectors-Oil-Resistant-PA-09/dp/B002AVVO7K?th=1))
5. Wire strippers
6. Assorted hex drivers

#### Assembly Instructions

1. Perform some quality control on you dowel pins. Make sure your M3 screws thread in nicely.
2. [Press the dowel pins into the carriage coupler plate](./toolchanger_carriage.md#coupling-plate-assembly). Make sure the threaded end of the dowel pin is facing out!
3. Screw the solder lugs into the dowel pins with the M3 screws. Align the tabs facing 'backwards', away from the dowel pin side of the carriage plate.
4. Solder the lugs together, using the pattern shown. Use lengths of wire that are as short as possible for the inter-lug connections. Right now the wires just float loosely. Somebody should modify the carriage plate so the wires can be neatly recessed. That could be you!

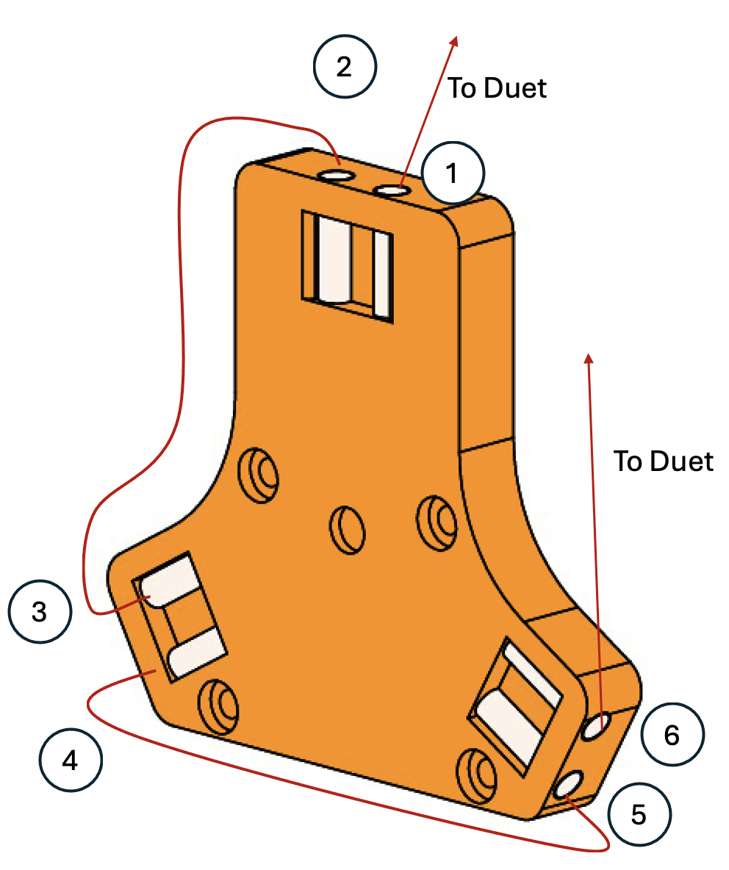
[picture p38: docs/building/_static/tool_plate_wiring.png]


Wired lugs will look like this:

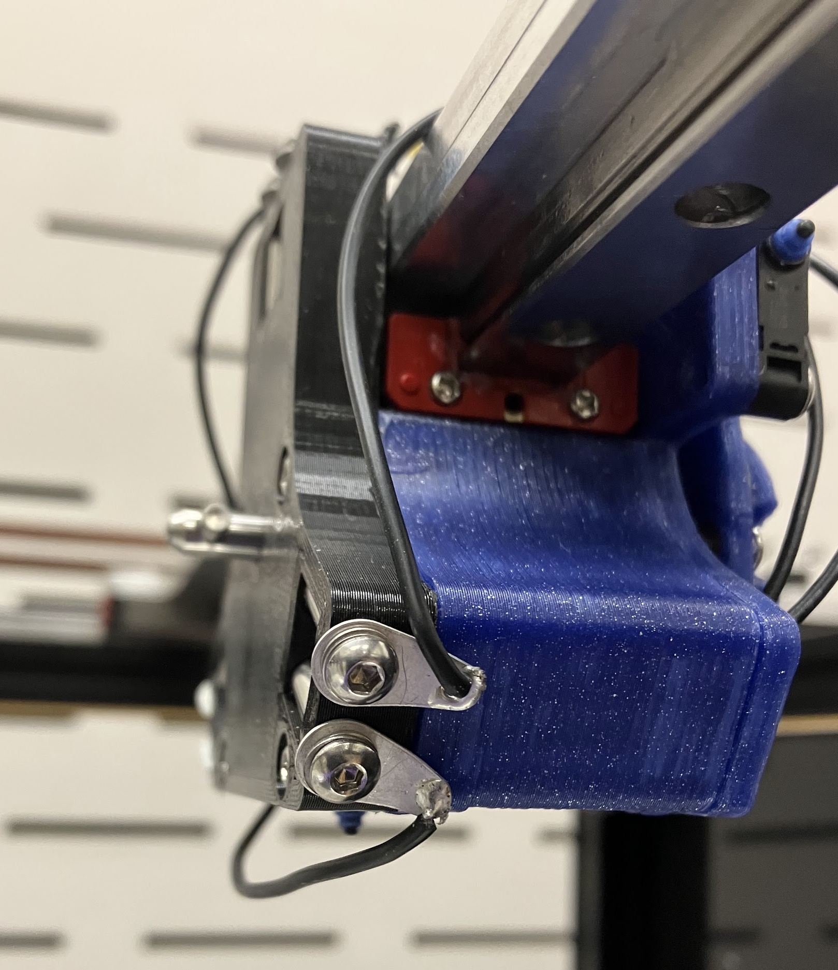
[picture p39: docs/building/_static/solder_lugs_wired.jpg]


| From | To |
|---| ---|
|Duet board | Pin 1|
| Pin 2 | Pin 3 |
|Pin 4 | Pin 5|
Pin 6 | Duet board |

5. Terminate the duet end of the wiring with molex terminals. Place the terminals in the 2 and 3 positions of the housing.
6. [Install the carriage plate on your toolchanger carriage.](./corexy.md#front-carriage-assembly). Your installed plate will look something like this.

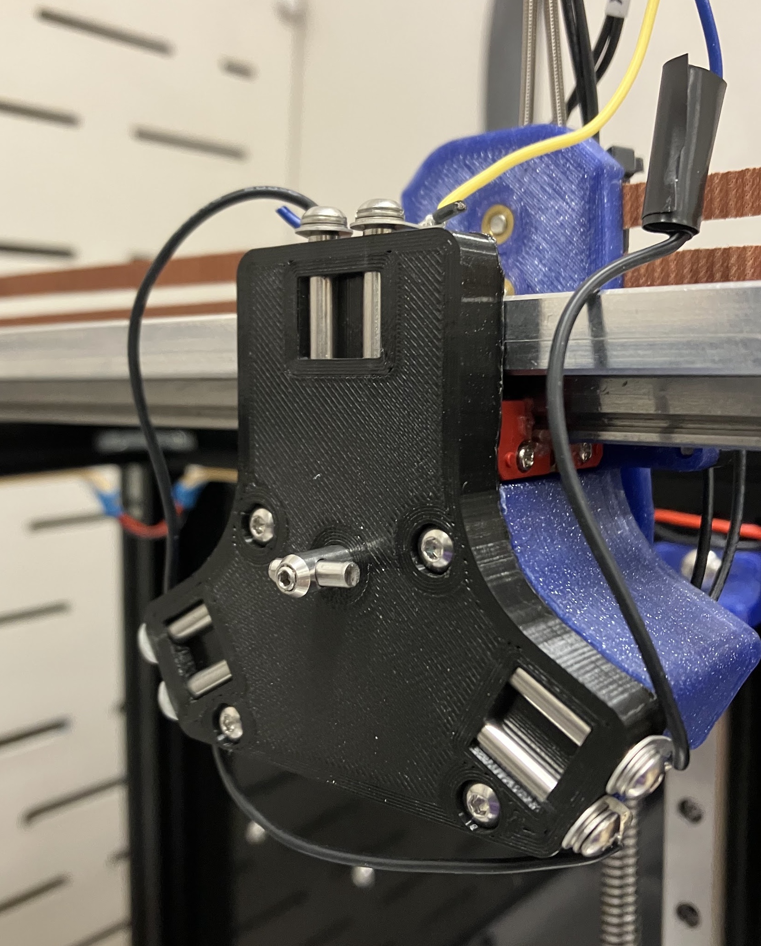
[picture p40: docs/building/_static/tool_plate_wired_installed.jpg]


7. Route the duet wires along the rest of the toolchanger wiring bundle back to your duet board
8. Plug the connector into an open IO port. We use io_3 in these instructions but any will do.

#### Configuration instructions

We will be configuring the tool ball switch as a Duet trigger. With a trigger activated, your duet will watch for a change in state on an external switch. When a change is detected, the defined action will be run. Here we will be using the trigger as an emergency stop. This will disable the steppers immediately and reset the board, the same as running the [M112 gcode](https://docs.duet3d.com/User_manual/Reference/Gcodes#m112-emergency-stop). You can read more on duet triggers [here](https://docs.duet3d.com/User_manual/Tuning/Triggers). We want our trigger to be active while a tool is in use, but we need to de-activate it whenever we park a tool, otherwise our machine will shut off when we do so. To accomplish this, we will define triggers in every tool pick-up macro and disable them before the tool is parked.

1. Add this line to your `sys/config.g` file. This will define your tool ball switch on the input that you are using. Change the input number to the connector that you plugged your wiring into.

```
M950 J0 C"^0.io3.in" ;define input 0 (J0) on connector board 0, io3, in pin, with pullup
```
Steps 2 and 3 will need to be done for every tool you want the crash detection to be active for.

2. Add the following lines to the end of the `tpost{n}.g` file of the tool you want to activate. Read more on the `M581` trigger gcode and it's parameters [here](https://docs.duet3d.com/User_manual/Reference/Gcodes#m581-configure-external-trigger)

```
M400; clears buffer of moves before proceeding.
M117 "initializing triggering on tool {n}" ; Debug print statement, remove if you want
M581 P0 T0 S1 R0 ; set up triggering
```

3. Add the following line to your `tfree{n}.g` file for your tool, immediately before the line that runs the tool_unlock.g macro. This will de-activate the trigger so the machine does not e-stop when you unlock the tool.

```
M581 P0 T0 S1 R-1 ; disable triggering
```

#### Testing crash detection

Gingerly test that the detection works with a tool that you don't care too much about. After picking up the tool, slowly push the bed up into the tip of the tool. At the first sign of deflection in the tool, the machine should disable steppers and reset.

If you are having issues with false positives while moving the tool around the bed without crashing it, try re-running the tool-lock macro after the tool has been picked up. This will give an extra cinch on the tool locking pin, holding the tool on tighter. You can test this by clicking on the `tool_lock.g` macro in the duet web control interface, and implement it permanently by adding another tool_lock line to your tool pickup macro. This might cause some long-term reliability issues with the tool changer interface or motor. We are still testing this. Alternatively, you could decrease the maximum acceleration of the X and Y axes in the machine configuration.

#### Future enhancements
Currently, this implementation emergency stops the machine. Recovering from this is a major hassle, requiring parking tools, clearing the bed, re-homing the machine, and re-starting any experiments. The `M581` trigger command can be configured to run an arbitrary gcode macro instead of e-stopping. A macro could be set up to pause the machine and publish a 'crash detected' message to HTTP or MQTT clients using the `M118` command. Our science-jubilee python interface could be modified to gracefully interrupt running experiments and notify the user when a crash is detected, enabling smoother recovery.

## StallGuard based crash detection

The Trinamic stepper motor drivers used in the Duet boards have stallGuard, a feature that allows the drivers to detect motor stalls. This would be ideal as it could allow for force-adjustable crash detection and could be always-on to detect issues when tools aren't active. However, the general consensus seems to be that stall detection is finicky and requires extensive tuning. We have looked into this option and could not figure out the Duet config to get it to work. Read more on it [here](https://docs.duet3d.com/User_manual/Connecting_hardware/Sensors_stall_detection).

## Computer vision based incident detection

Our third idea for incident detection is to use a computer vision system to monitor a video feed of Jubilee. The system could be trained on examples of correct operation and common incident scenarios. This would have the benefit of flagging non-crash incidents that could impact experiments, such as missed pipette tip pickups, but might struggle to detect edge-case crash incidents. We have not looked into options for implementing this.

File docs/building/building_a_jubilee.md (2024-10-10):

---
title: Science Jubilee Build Instructions
---

(jubilee-build-resources)=
# Science Jubilee Build Instructions

So, you're ready to build a Science Jubilee! This guide is a complete set of instructions to get you set up and running, from hardware and tools to building and software setup.

To supplement the text, we also have an ongoing series of build along videos. Check out the intro here:

```{youtube} 8JUbr9aU8eQ
```

## Hardware

The parts to build a Jubilee have been consolidated into [a kit by Filastruder](https://www.filastruder.com/collections/jubilee/products/jubilee-motion-platform-kit). No royalties are provided to Machine Agency for these sales, but Filastruder works with Machine Agency to ensure the parts are of suitable quality and tolerance.

We recommend the following kit options for a Science Jubilee build:

| Option Category | Selection |
| --- | --- |
Extrusion Anodization Color| `Purple` or `Blue` |
| Printed Parts Color[^prints] | `Orange`, `Blue`, or `Black` |
| Panel Options | `Back and side panels (white)` |
| Bed Plate Options | `PEI Plate and Magnetic Sticky Sheet` |
| Bed Heater Options[^heater] | `None` |
| Electronics[^duet] | `Duet 3 Mini Ethernet + 3HC (up to 2 tools)` |
| Electronics Expansion | `+1 3HC Expansion (up to 5 tools total)` |

**NOTE: You will also need to purchase [a Raspberry Pi 5 kit](https://www.raspberrypi.com/products/raspberry-pi-5/?variant=raspberry-pi-5-desktop-kit-us) separately**[^duet].

Check out the Sourcing video to to see how to order the kit:
```{youtube} or2Qg8UBInM
```

[^prints]: Luke's Laboratory also sells [a set of Jubilee 3D printed parts](https://lukeslabonline.com/products/jubilee-printed-parts-kit-asa?variant=40134863651001) in case the 3D printed parts are out of stock on Filastruder. This is the recommended option for Science Jubilee, and the build instructions here are based on the specific configuration in the kit. No royalties are given to us; however, Filastruder and Lukes Laboratory work with us to ensure the parts are of suitable quality and tolerance to meet the needs of a Jubilee build.
[^heater]: `None` assumes you don't plan to use it as an FDM 3D printer or perform experiments with the entire bed heated; otherwise, you can choose `120v, 750W Keenovo Heater w/ 150C Thermal Cutoff & SSR` (assumes North America).
[^duet]: Both the Ethernet and WiFi version can be controlled via a Raspberry Pi (e.g., RPi 4B, RPi 5) by directly connecting to the Duet 3 Mini, which we recommend. This allows you to connect to a variety of WiFi networks (e.g., WPA2-Personal, WPA2-Enterprise), which means connecting to networks such as Eduroam is supported. By contrast, the `Duet 3 Mini WiFi + 3HC` (without a Raspberry Pi connected) can only connect to 2.4 GHz WPA2-personal networks, which means 5G networks and networks like Eduroam typical of academic, government, and industry settings are not supported. While both the Ethernet and WiFi `Duet 3 Mini + 3HC` versions can be used with a Raspberry Pi, we recommend the Ethernet version primarily because it can simplify troubleshooting if you have any issues with the Raspberry Pi Duet 3 Mini firmware. Aside: For laboratory automation in general, you may consider [implementing a standalone IoT network](https://github.com/sparks-baird/self-driving-lab-demo/discussions/83) to support microcontrollers such as the Raspberry Pi Pico W, which can be used within custom Jubilee tools.

### Recommended upgrades

Mandala Rose Works produces aluminum upgrades for several components on Jubilee. Replacing stock PLA 3D printed parts with their aluminum counterparts can increase the reliability and solvent compatibility of the motion platform. These upgrades are listed in order of their priority in our view. If you plan to use the OT2 pipette tool on your Jubilee, you should purchase the aluminum Z yokes.

| Part | Link | Reason to upgrade |
| --- | --- | ---|
| Z yokes | https://mandalaroseworks.com/products/jubilee-machined-yokes | Allows use of a zip tie or pony clamp to prevent bed-tip issues |
| Front Corner Brackets | https://mandalaroseworks.com/products/jubilee-front-corner-brackets | Improved durability of bracket. Note: requires 6 M5x25mm screws to install |
| CoreXY Stepper mounts | https://mandalaroseworks.com/products/jubilee-aluminum-stepper-mounts | Improved pulley alignment and durability. Note hardware requirements listed at link |
| Z motor mount plates | https://mandalaroseworks.com/products/jubilee-machined-zplates | Improved solvent resistance. Looks cool |
| Tool changer carriage | https://mandalaroseworks.com/products/jubilee-machined-carriage | We haven't used these but have heard they are nice |

## Tools

You will need to procure some tools on your own, but some are already available in the Filastruder kit.

### To Buy
- Calipers [[US Amazon](https://www.amazon.com/Neiko-01407A-Electronic-Digital-Stainless/dp/B000GSLKIW)]
- Wire Cutters [[US Amazon](https://www.amazon.com/Hakko-CHP-170-Micro-Cutter/dp/B076M3ZHBV)]
- SN-2549 Wire Crimpers [[US Amazon](https://www.amazon.com/gp/product/B01N4L8QMW)]
- Arbor Press [[US Amazon](https://www.amazon.com/Palmgren-AP05-0-5-Arbor-Press/dp/B01MQD4CNR)]
- Soldering iron [[US Amazon](https://www.amazon.com/Weller-SP40NUS-40-Watt-Soldering-Iron/dp/B00B3SG6UQ?th=1)] (*treat this one as dedicated tool meant only for heat set inserts*)
- Thin flathead screwdriver (*for replacing the default soldering tip with the heatset insert tip*) and Phillips-head screwdriver (*for (un)screwing terminal plugs on the power supply*) [[US Amazon, 6-piece set](https://www.amazon.com/Magnetic-Screwdriver-Professional-Screwdrivers-Improvement/dp/B08XY5C41N/) (untested)]
- 4" reusable cable ties [[US Amazon](https://www.amazon.com/Adjustable-Organizer-Multi-purpose-Management-Organizing/dp/B0CJ52WJZY/?th=1)]
- 8" reusable cable ties [[US Amazon](https://www.amazon.com/Adjustable-Organizer-Multi-purpose-Management-Organizing/dp/B0CJ4W5VN5/?th=1)]

### Already included in kit
Certain tools are already included in the Filastruder kit. This information is included for your reference.
- Hex key 1.5 mm (not ball end) (alternative: [[1.5 mm ball end hex key, US McMaster-Carr](https://www.mcmaster.com/5497a51)])
- Ball end hex keys (2.0 mm, 2.5 mm, 3.0 mm) (alternatives: [[2.0 mm, US McMaster-Carr](https://www.mcmaster.com/5497a52)], [[2.5 mm, US McMaster-Carr](https://www.mcmaster.com/5497a53)], [[3.0 mm, US McMaster-Carr](https://www.mcmaster.com/5497a54)], NOTE: the ones from the kit do not include a grip handle)
- 2-pack of 4-inch Quick-Grip Clamps (NOTE: you will need to remove the pin on the end of the bar; alternative [US Amazon](https://www.amazon.com/IRWINQUICK-GRIPOne-Handed-Micro-Clamp-Pack-1964747/dp/B00004SBCO) (no modification required))
- Threadlocker Blue (2.5 mL) (alternative: [Vibra-Tite](https://www.amazon.com/Permatex-24200-Medium-Strength-Threadlocker/dp/B0002UEMZ2))
- M3-M4 Heatset Insert Installation Tip (alternative: [[US McMaster-Carr](https://www.mcmaster.com/92160a115)])
- Set of 2 25-50-75mm machinist blocks (alternative: [[US Amazon](https://www.amazon.com/BL-25-50-75-Pair-Precision-Steel-Blocks/dp/B002HIYZJU)])
- M3 Hex Nut Driver (alternatives: [[Filastruder](https://www.filastruder.com/products/5-5mm-nut-driver?variant=17989593104455)], [[US Amazon](https://www.amazon.com/gp/product/B00G2DNXV2/ref=ppx_yo_dt_b_asin_title_o01_s00?ie=UTF8&psc=1)])
- 100-pack of 2.5mm (0.1in.) thick zip ties

### Additional Notes

You will also need a flat surface during assembly, ideally one that is somewhat heat tolerant when dealing with heatset inserts. Wear protective eyewear (e.g., [[US Amazon](https://www.amazon.com/BK310AF-Polycarbonate-Anti-Fog-Safety-Non-Slip/dp/B009A658JS/)]) while working with hand tools, especially while using a soldering iron, cutting springs, and press-fitting components.

(assembly-instructions)=
## Assembly Instructions

The instructions must be completed sequentially from Section 1 to Section 3. Instructions in the same section don’t explicitly depend on each other, so they can be done at the same time with a friend. In total, plan for ~30 hours within a full week to complete a first-time build.

```{tip}
We recommend isolating the build window to within a week and building with no more than two or three individuals in total. This will help reduce the startup cost of picking up where you left off and minimize issues that might come up from poor understanding of the full system. Ideally, all individuals should be involved from the beginning of the process.
```

```{toctree}
:maxdepth: 1
:caption: Prerequisite Knowledge

prerequisite_knowledge
```
```{toctree}
:caption: Part Prep
:maxdepth: 1

heatset_inserts
corner_brackets
```
```{toctree}
:caption: Section 1: Module Assembly
:maxdepth: 1

outer_frame
motor_plate
corner_plate
crossbar
REL
toolchanger_carriage
build_plate
panel
```
```{toctree}
:caption: Section 2: Frame Assembly
:maxdepth: 1

lower_frame
corexy
```
```{toctree}
:caption: Section 3: Final Assembly and Tuning
:maxdepth: 1

z_axis
```

```{toctree}
:caption: Enhancements
:maxdepth: 1

tool_crash_detection
```

### Videos

In addition to the pdf instructions, we created a [YouTube playlist for certain steps of the build process](https://www.youtube.com/watch?v=8JUbr9aU8eQ) that may be of help.

## Additional Jubilee Resources

- [Jubilee Wiki](https://jubilee3d.com/index.php?title=Main_Page). This is the main documentation hub for the Jubilee project. We encourage you to look through the resources organized on the left-hand sidebar--there's a lot of info there! While not all pages on the wiki will be relevant for lab automation, many help demonstrate Jubilee functionality.
- [Jubilee Discord](https://discord.gg/jubilee). The Jubilee Builders and Extenders Discord is actively used by the Jubilee Community. If you have a question about a build step or troubleshooting your machine, this is a great place to get help! Discussion is organized by topic--you may be interested in the `#lab-automation` channel, for example.
- [Lab Automation Discord](https://discord.gg/ubxU2rMJwN). The open lab automation discord is a focused on lab automation with a heavy Jubilee bent. This is the best spot to ask questions about Jubilee's capabilities with regard to your science.
- [Sourcing parts independently](https://jubilee3d.com/index.php?title=Getting_Parts). If you'd prefer to source parts yourselves rather than buy a kit from Filastruder, https://jubilee3d.com has a section with a shopping list and other recommendations.
- [(Original) Jubilee Assembly Instructions](https://jubilee3d.com/index.php?title=Assembly_Instructions). These are the original Jubilee build instructions from which the Science Jubilee build instructions are based on.

## Footnotes

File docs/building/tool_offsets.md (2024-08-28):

---
title: Setting Toool Offsets
---

(tool-offsets)=
# Setting Tool Offsets

Once you have defined your tool in the Duet config file and set [tool parking post positions](parking_posts.md), the last step in setting up a new tool is to set offsets. Tool offsets record the location of the 'active point' of the tool relative to the z-probe on the tool carriage, which is Jubilee's default reference point. Accurate offsets allows Jubilee to position each tool using the same coordinate system. For example, if your experiment involves pipetting reactants into a wellplate's 'A1' well, then recording the reaction in that well with a spectroscopy probe, accurate offsets will allow Jubilee to position both tools over the center of well A1.

## Skills and capabilities needed
- Interacting with Jubilee over Duet web control
- Editing gcode configuration files

## Equipment and supplies needed
- A tool, with parking post positions already set
- Some masking or label tape
- A fine-point pen

## Set up your `toffsets.g` file

Offsets should be set in a config file called `toffsets.g`. Depending on how you initially set up your Jubilee, you may have tool offsets defined in config.g. We reccomend storing them in `toffsets.g`, because this allows you to update the tool offset values without restarting (and re-homing) your machine. This will make your life far easier if you are setting up multiple tools. Set the offsets of your tool to all zeros for now.

```{tip}
If you are updating offsets on an existing tool, set the existing offsets to 0. This will make the math much easier later.
```

To move to the `toffsets.g` format:
1. Remove any `G10` commands from your Jubilee's `config.g` file
2. Add the line `M98  P"/sys/toffsets.g"` to the end of your `config.g` file
3. Save your `config.g` file
4. Create a file called `toffsets.g` in `:/sys` on the Jubilee duet file system.
5. For every tool you have defined, add the line `G10 P{tool_index} X0 Y0 Z0` to the `toffsets.g`file
6. Save `toffsets.g` and restart your Jubilee

From now on, any time your make changes to a tool offset value in `toffsets.g`, you can load the new value by running the command `M98 P"/sys/toffsets.g"` from the g-code command line in duet web control.

## Determine your tool's active point

The active point of the tool is the relevant reference point on the tool for the tool's functionality. For a pipette tool, this is the tip of the pipette barrel (without a tip attached). For a spectroscopy probe, this would be the optical tip. For a camera, this is likely the center of the field of view, but this will depend on the downstream software use.

## Place an X on the Jubilee bed

Using the masking tape and a pen, draw and 'X' on the bed somewhere. This will be your reference point for calculating offsets. Position the 'X' such that the bed can be raised to touch the tool carriage without the lab automation deck plate interfering, and so that the active point of the tool can reach it. Beyond this, the exact position does not matter.

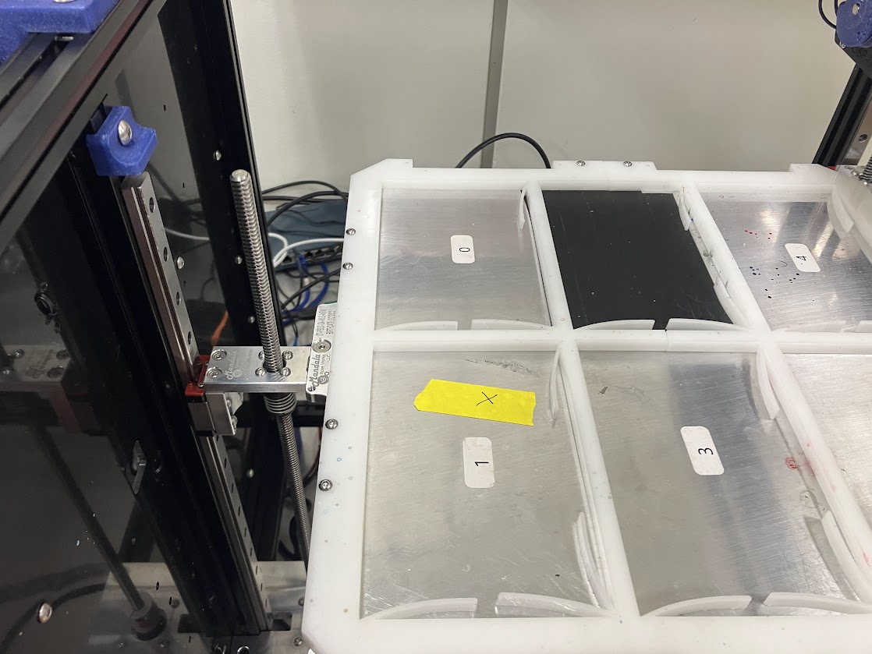
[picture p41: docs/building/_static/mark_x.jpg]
```{figure} _static/mark_x.jpg
```

## Record 'X' position with Jubilee reference point

Record the location of the X relative to the Jubilee tool reference point, which is the z-axis limit switch.

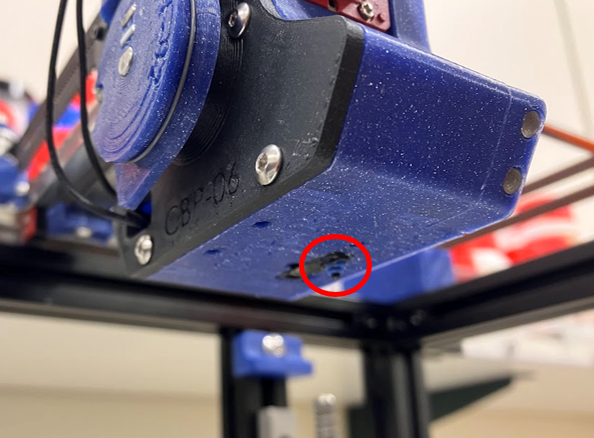
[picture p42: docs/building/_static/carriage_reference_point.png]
```{figure} _static/carriage_reference_point.png

The limit switch on the underside of the tool carriage is the default reference point.
```

1. Make sure no tools are picked up or active
2. Position the tool carriage over the 'X' you marked
3. Carefully line up the tool carriage's Z axis limit switch over the X. This will require squinting and viewing the limit switch from different angles. A flashlight may be helpful as well.
4. Record the X and Y position of the tool carriage for later use.

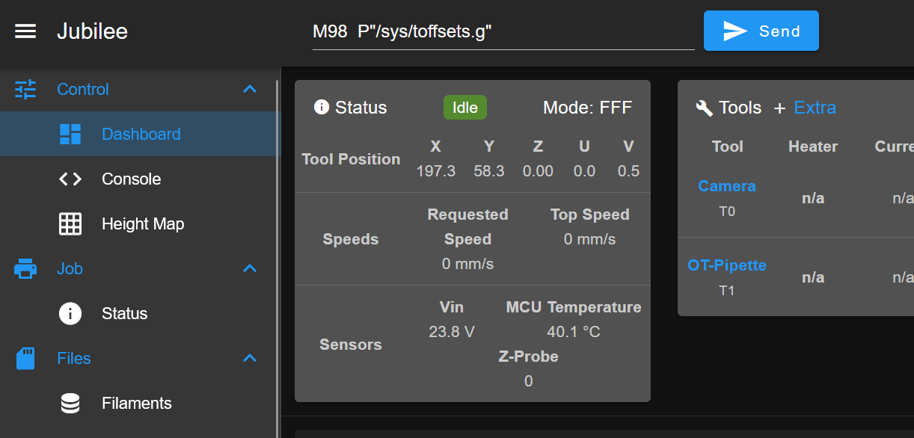
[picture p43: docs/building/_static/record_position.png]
```{figure} _static/record_position.png

Record the position reported on the Duet web control dashboard.
```

## Pick up your tool

:::{warning}
The bed will not automatically drop when you pick up the tool because you have not set up Z offsets yet. MAKE SURE TO DROP THE BED SO THAT IT CLEARS THE TOOL before picking up the tool.
:::

1. Drop the bed such that the tool will clear it when picked up
2. Pick up the tool by running the `T{toolindex}` command

## Position your tool over the 'X'

- As before with the Jubilee z-axis limit switch, position the active point of your tool directly over the 'X' mark. The tool should be directly over the X. Raise the bed until it is just barely not touching the tip of the tool.
- Record the XYZ position of the tool

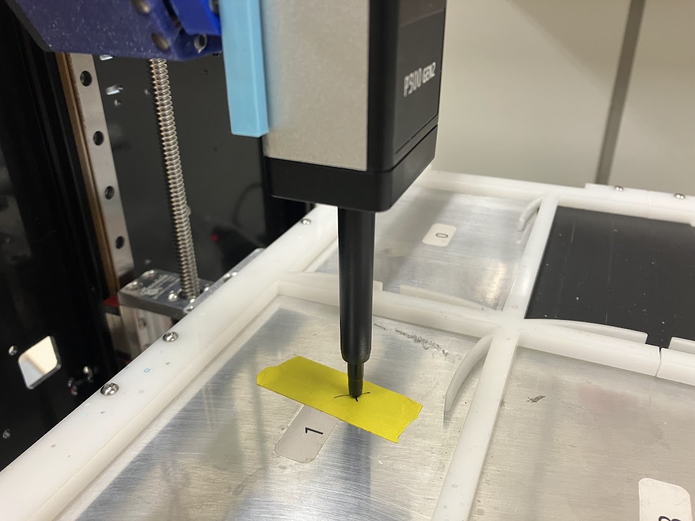
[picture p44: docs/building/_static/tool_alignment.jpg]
```{figure} _static/tool_alignment.jpg
```

## Calculate tool offsets from recorded positions
To calculate the offsets, subtract the tool position from the carriage position.

Example:
- Carriage reference point position: (X = 196.9, Y = 58.6, Z = 0)
- Tool reference point position: (X = 198.0, Y = 19.6, Z = 100.8)

| Axis | Carriage position | Minus | Tool position | Equals | Tool offset |
|---|---|---|---|---|---|
| X | 196.9 | - | 198.0 | = | -1.1 |
| Y | 58.6 | - | 19.6 | = | 39.0 |
| Z | 0 | - | 100.8 | = | -100.8 |

## Update tool offsets

Update the tool offsets in the appropriate line of your `toffsets.g` file. If the above calculated offsets were for tool index 1, the updated G10 command would look like `G10 P1 X-1.1 Y39.0 Z-100.8`.

## Verify offsets were set correctly

- Load the new tool offsets by running `M98 P"/sys/toffsets.g"`
- If your did not move your tool, it should still be located directly over the 'X' mark. The position reported for the tool from the Duet web control interface should now be the same as the position you recorded for the empty carriage.

That's it!

## Notes

- If you have multiple tools on your machine, it is best to update offsets for each tool every time you do offsets for any tool. This will help cancel out any errors or uncertainty in the tool carriage reference point position determination step.
- If you have a fleet of tools to align, frequently reconfigure your machines, or just hate repetitive manual tasks that could be automated, consider using [tool alignment with machine vision](https://github.com/HaythamB/TAMV/) to automate the alignment process.

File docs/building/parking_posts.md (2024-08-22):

---
title: Setting Parking Post Positions
---

(parking_posts)=
# Setting parking post positions

Tool parking posts keep tools accessible but out of the way when they are not in use. Correctly setting parking post positions is critical to smooth, reliable tool changes with your Jubilee. The process of setting parking post positions involves determining and recording the X and Y positions of the parked tool, adjusting the Z height of the parking post, and configuring the appropriate tool change macro files.

## Skills and capabilities needed
- Interacting with Jubilee over Duet web control
- Editing gcode configuration files

## Selecting an appropriate parking post for your tool

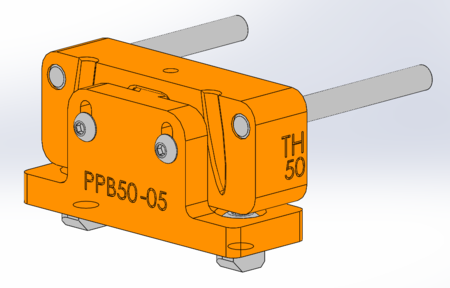
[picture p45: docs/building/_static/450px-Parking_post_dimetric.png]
```{figure} _static/450px-Parking_post_dimetric.png
:scale: 100 %

A rendering of an assembled Jubilee tool parking post. Image from https://jubilee3d.com/index.php?title=Tools.
```

Jubilee tool parking posts come in various sizes to accommodate different tool sizes. If you are building an existing tool design from the `science-jubilee` project, the tool documentation should provide the correct parking post STL files. If you are building a new tool, you will need to either design your tool wing spacing around an existing parking post width, or modify the parking post design to fit your tool. [Parking post assembly instructions](https://github.com/machineagency/jubilee/blob/main/tools/jubilee_tools/tool_posts/configurable_tool_post/assembly_instructions/parking_post_assembly_instructions.pdf) are available at the main Jubilee project repository. [More parking post information](https://jubilee3d.com/index.php?title=Parking_Post) can be found on the Jubilee project wiki.

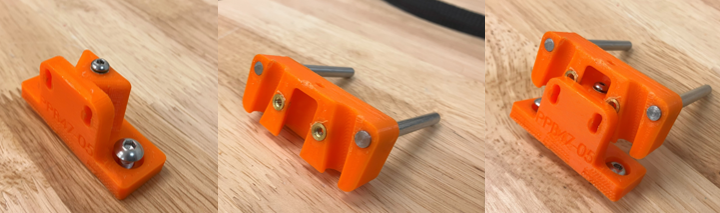
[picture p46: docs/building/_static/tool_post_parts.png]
```{figure} _static/tool_post_parts.png
:scale: 50 %

Left: Parking post base. Middle: Parking post tool holder. Right: Base and tool holder assemble like this.
```

## You will need

1. An assembled, configured Jubilee
2. A new tool to be parked
3. An appropriate parking post for your tool, assembled (see above)
4. 1.5mm and 2.5mm hex keys, either in an L-key or screwdriver format (exposed hex key shaft is required to reach recessed fasteners)

## Placing the parking post on Jubilee

1. Fasten your parking post loosely to the front top extrusion piece of your Jubilee. Use the T-nuts you inserted during assembly. If you ran out of T-nuts, you will need to use drop-in M5 T-nuts.
2. Position the parking post where you would like on the extrusion, and tighten the parking post base screws with your 2.5mm hex key. When placing your parking post, consider the spacing required between tools, the total number of tools you will have on your Jubilee, and any obstructions that may interfere with low-hanging tools like the front Z leadscrews.

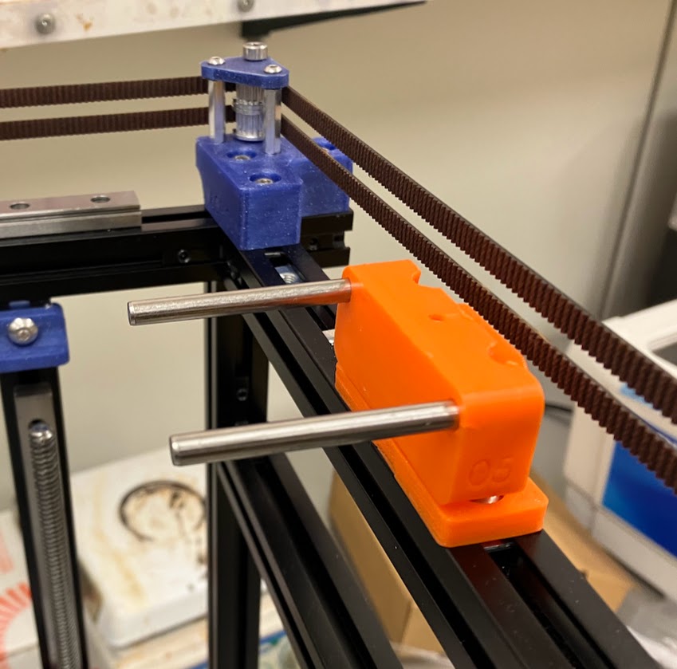
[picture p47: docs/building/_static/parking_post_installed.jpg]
```{figure} _static/parking_post_installed.jpg
:scale: 50 %
```
```{youtube} EEWD-wCFl9g
```

:::{warning}
Make sure to drop the bed z height so that the tool will clear the bed when picked up. This will not happen automatically becuase you have not set the tool offsets yet!
:::

## Determining parking post X position
Next determine the X position of the parking post by manually 'parking' a tool with the Duet web control jog controls.

1. Place the tool changer carriage somewhere near the middle of the bed.
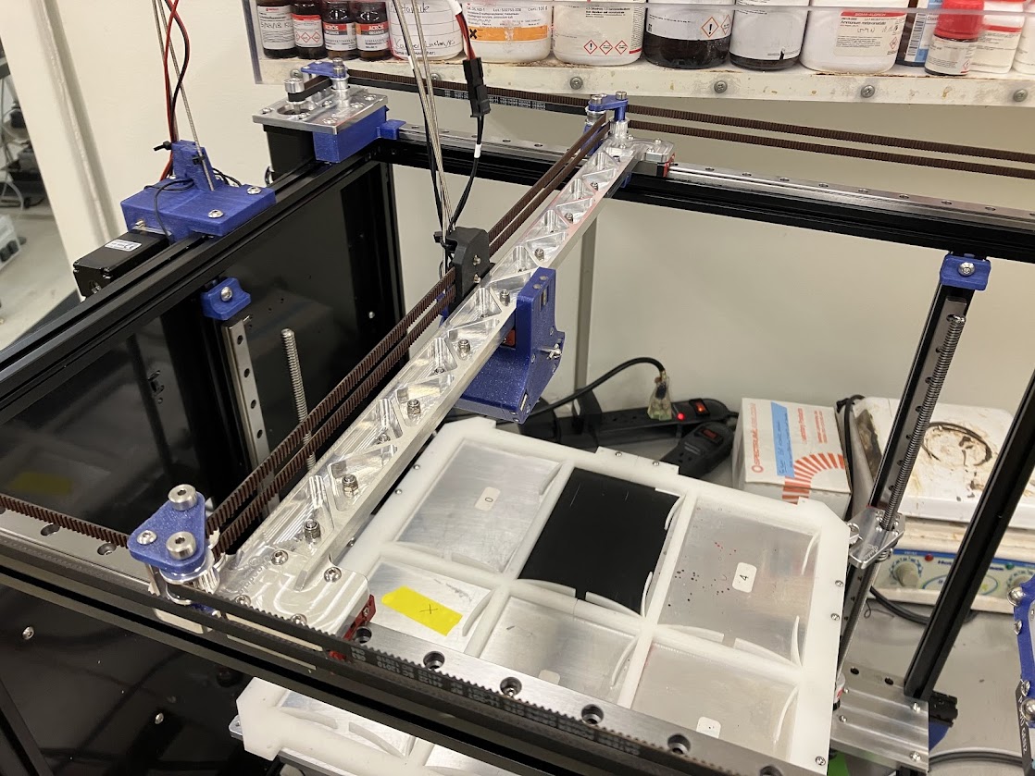
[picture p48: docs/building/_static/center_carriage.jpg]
```{figure} _static/center_carriage.jpg
:scale: 50 %
```
2. Drop the bed sufficiently so that tool you are adjusting will clear the bed.
3. Make sure the U (tool changer) axis is homed
4. Manually attach the tool to the carriage by aligning the tool balls to the kinematic coupling pins, then locking the tool changer mechanism by clicking on the 'tool_lock.g' macro in the Duet web control interface

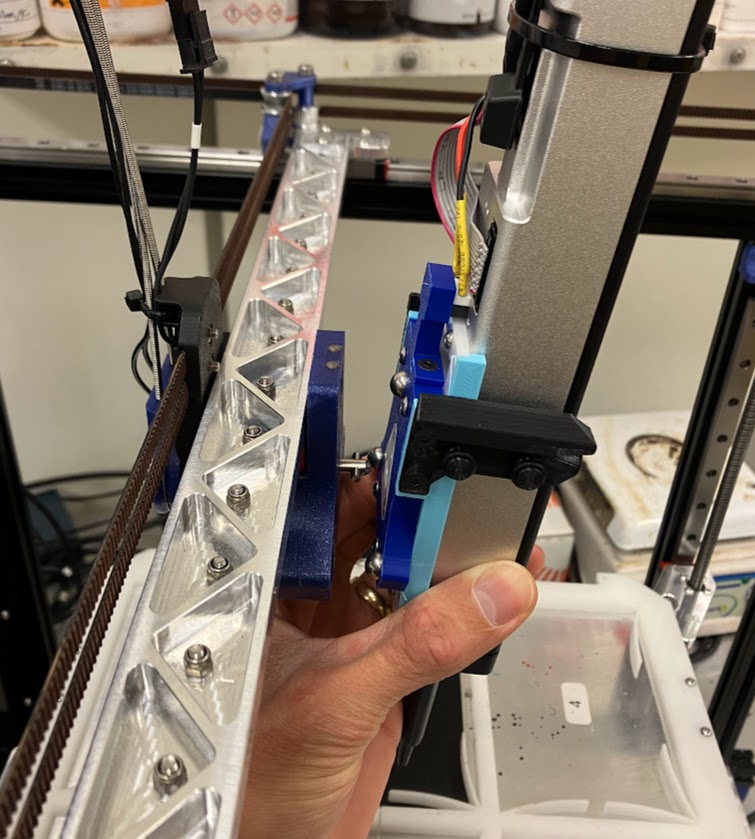
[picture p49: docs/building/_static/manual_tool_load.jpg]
```{figure} _static/manual_tool_load.jpg
:scale: 50 %

Manually position the tool on the tool carriage
```

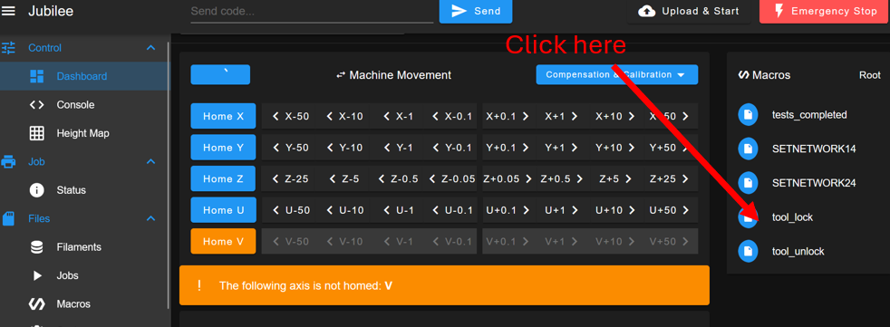
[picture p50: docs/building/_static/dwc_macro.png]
```{figure} _static/dwc_macro.png
:scale: 50 %

While still holding the tool on the carriage, run the `tool_lock.g` macro from Duet web control
```
5. Move the tool carriage so that it is approximately near the location of the tool post.
6. Carefully align the tool so that the tool wings slide onto the tool post. Iteratively move the tool in X and Y, lining up the tool wings so there is an even gap between the wings and the post on both sides
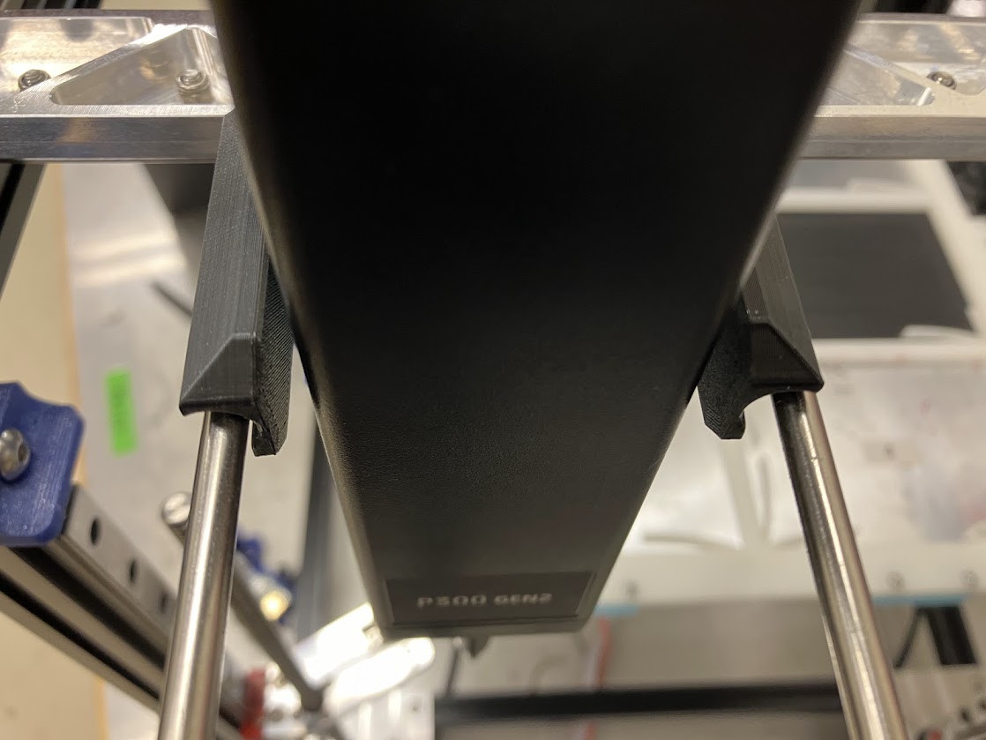
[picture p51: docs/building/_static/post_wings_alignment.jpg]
```{figure} _static/post_wings_alignment.jpg
:scale: 50 %

This tool is too far to the left, evidenced by the uneven gap between the tool wings and the tool posts.
```
7. You may need to adjust the Z height of the tool post at this point to accommodate the tool. See below for how to do this.
8. Once you are happy with the X positioning of your tool, record the X position of the tool carriage.

## Setting parking post Z height

The parking post Z height will need to be adjusted so that the tool alignment balls and toolchanger lock slot align with the toolchanger carriage pins and toolchanger lock pins. Because the tool carriage does not have a height adjustment, this is done with the Z height adjustment of the tool post.

1. Remove the tool from the carriage (run the 'tool_unlock.gcode' macro), then place the tool on the tool post
2. Determine if the tool needs to move up or down. You can do this by:
    - Move the tool carriage to the 'X' value you already identified for the tool post, then slowly move the carriage into the tool in the Y direction. Watch the interface between the tool changer locking pin and the slot on the tool. Does the pin enter the middle of the slot without touching the Delrin, or does it catch on the top or bottom of the slot?
    - Move the tool carriage into the tool plate slot, and manually lock/unlock the toolchanger with the appropriate macros. Is the tool visibly pulled up or down as the toolchanger locks?
    - Pick up the tool with the tool carriage, remove it from the post by moving the carriage back in Y, and replace the tool on the post. Are the tool wings lined up with the tool posts or are the posts high/low?
3. Adjust the toolchanger Z height.
    - Lossen the two tool holder fixing screws on the back of the tool post
    - Adjust the Z height adjustment screw: Loosen it to raise the tool holder, tighten it to lower. If you are lowering the tool post, the tool holder may catch on the base and need to be pushed down by hand to adjust.
    - Tighten the tool holder fixing screws

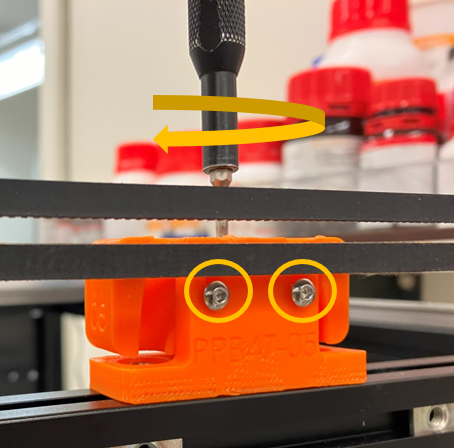
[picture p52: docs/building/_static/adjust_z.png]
```{figure} _static/adjust_z.png
:scale: 50 %
```
4. Repeat steps 2 and 3 until you are happy with your height

This video also describes the process:

```{youtube} _3stUKidY7Y
```

## Determine pick up and drop off Y position

Next decide on Y positions for tool pickup and drop-off. For most tools, a drop-off position of 333mm and a pick-up position of 335mm works well, but experiment with your tools. Having a slightly larger tool pick-up position ensures that the tool carriage makes good contact with the tool during pickup and prevents missed tool changes.

## Setting parking post positions in Duet configuration

You will need to edit 3 files to set the parking post position in the Duet configuration:
1. tpre{n}.g - defines pick-up preparation behavior
2. tpost{n}.g - defines pick-up behavior
3. tfree{n}.g - defines drop-off behavior

The {n} in the filename is replaced with the tool index for your tool. For tool index 0, the tpre file name is `tpre0.g`. You defined tool indices when you added your tool to the Jubilee's `config.g` file, so check there if you do not know your tool indices.

1. Set your tool post positions in the tpre{n}.g file. Below is a sample tpre0.g file. Replace <X_position> with the value for your tool post.

```gcode
; tpre0.g
; Runs after freeing the previous tool if the next tool is tool-0.
; Note: tool offsets are not applied at this point!

G90                   ; Ensure the machine is in absolute mode before issuing movements.
G0 X<X_position> Y280 F20000 ; Rapid to the approach position without any current tool.
G60 S0                ; Save this position as the reference point from which to later apply new tool offsets.
```
The `Y280` value in the `G0` command here sets the maximum Y value that the machine will approach to while making X moves. In other words, the machine will make a diagonal move to X = <X_position>, Y = 280, then proceed to make Y-only moves until the tool has been picked up. This prevents the tool carriage from colliding with parked tools. If you have particularly large tools, you may need to decrease the Y value from 280, but this is a sensible default.

2. Set your tool post positions in the tpost{n}.g file. Edit the X and Y values in lines 11 and 12.

```gcode
; tpost0.g
; called after firmware thinks Tool0 is selected
; Note: tool offsets are applied at this point!
; Note that commands preempted with G53 will NOT apply the tool offset.

; M116 P1                    ; Wait for set temperatures to be reached
; M302 P1                    ; Prevent Cold Extrudes, just in case temp setpoints are at 0

G90                        ; Ensure the machine is in absolute mode before issuing movements.

G53 G1 X<X_position> F6000           ; Move to the pickup position with tool-1.
G53 G1 Y<Y_pickup_position> F6000
M98 P"/macros/tool_lock.g" ; Lock the tool

G1 R2 Z0                   ; Restore prior Z position before tool change was initiated.
                           ; Note: tool tip position is automatically saved to slot 2 upon the start of a tool change.
                           ; Restore Z first so we don't crash the tool on retraction.
G1 R0 Y0                   ; Retract tool by restoring Y position next now accounting for new tool offset.
                           ; Restoring Y next ensures the tool is fully removed from parking post.
G1 R0 X0                   ; Restore X position now accounting for new tool offset.
```

3. Set positions in tfree{n}.g file. Set the X_position and Y_dropoff_positions. If you changed the Y=280 pre-positioning value in tpost.g, change that value here as well in line 9.

```gcode
; tfree0.g
; Runs at the start of a toolchange if the current tool is tool-0.
; Note: tool offsets are applied at this point unless we preempt commands with G53!

G91                          ; Relative Mode.
G1 Z10                        ; Pop Z up slightly so we don't crash while traveling over the usable bed region.
G90                          ; Absolute Mode.

G53 G0 X<X_position> Y280 F12000    ; Rapid to the back of the post. Stay away from the tool rack so we don't collide with tools.
                             ; This position must be chosen such that the most protruding y face of the current tool
                             ; (while on the carriage) does not collide with the most protruding y face of any parked tool.

G53 G1 Y<Y_drop off position> F6000            ; Controlled move to the park position with tool-1. (park_x, park_y)
M98 P"/macros/tool_unlock.g" ; Unlock the tool
G53 G1 Y305 F6000            ; Retract the pin.
```

## Test tool pick-up and drop off

Now you should be able to pick up and drop off your tool. The gcode command to pick up a tool is `T{n}`, and to drop off is `T-1` (regardless of tool index). You should now be able to run these commands and repeatably pick up and drop off your tool.

Once a tool is picked up, it should be securely held by the tool changer mechanism. There should be no play in the kinematic coupling when the tool is lightly twisted. If there is play, the most likely cause is poor tool post aligment and Z height adjustment. Play could also be due to an improperly assembled tool changer mechanism.

## Up next

Now you are ready to [configure tool offsets](../getting_started/new_user_guide.md#setting-tool-parking-post-positions-and-offsets) for your new tool.

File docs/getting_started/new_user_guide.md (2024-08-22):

---
title: New User Guide
---

(new-user-guide)=
# New User Guide
This page provides a general overview of the Jubilee ecosystem with an eye towards getting a new contributor up to speed as a developer of Jubilee for science. This guide was developed as a resource to aid in the onboarding of new students in the Pozzo research group, but can serve as a useful reference for anyone new to Jubilee. If you are using a Jubilee as a tool in your research in collaboration with an established Jubilee user, following this guide verbatim may be unnecessarily involved. However if you are starting from scratch with Jubilee, you will need to follow all the steps here to get a functional experiment up and running.

## What is Jubilee?

To lift directly from the Jubilee wiki, ["Jubilee is an extensible multi-tool motion platform capable of running G-code for low force automation applications."](https://jubilee3d.com/index.php?title=Main_Page). Jubilee is originally developed and configured as a tool-changing 3D printer. Tool changing 3D printers use multiple hot-swappable extruder heads to allow them to print with multiple colors or materials. Jubilee is a great platform for experimental automation because the tool changing capability makes it possible to run multi-step experimental workflows on a single platform without moving samples manually. The open, extensible nature of the platform also makes it reasonably straightforward to develop new tools or capabilities. However, because Jubilee is an open-source system, the user is responsible for many aspects of building and running the system. This lends Jubilee a steep learning curve compared to other automation platforms. This guide provides a pathway to flatten that learning curve.

## Where to find help?

Because Jubilee is many things to many people, information on the platform is spread across several locations.

- The Jubilee wiki page [https://jubilee3d.com/index.php?title=Main_Page](https://jubilee3d.com/index.php?title=Main_Page) is the official website of the Jubilee project. You will find instructions for [building the core motion platform](https://jubilee3d.com/index.php?title=Assembly_Instructions) and configuring it as a 3D printer here.
- Jubilee as a 3D printer has a large and active community. The [Jubilee discord](https://discord.gg/RxMaGJdGH9) is the best spot to interact with this community. (Open a github issue on science_jubilee if this link is broken)
- The people behind science-jubilee host an Open Source Lab Automation discord server. Join at [https://discord.gg/ubxU2rMJwN](https://discord.gg/ubxU2rMJwN).
- Jubilee uses a commercial motion control board called Duet as its brains. For software, configuration, or wiring issues, start at the [Duet documentation](https://docs.duet3d.com/).

## Prerequisites

This guide assumes you have a few things:

### Hardware:

1. A Jubilee motion platform, either assembled or still in the box (in the box is better!). You can purchase a Jubilee kit from [filastruder](https://www.filastruder.com/collections/jubilee/products/jubilee-motion-platform-kit) or assemble the requisite parts from the [bill of materials](https://jubilee3d.com/index.php?title=Getting_Parts). If it is an option, buying the Filastruder kit is likely to be the most cost effective option, doubly so if you value your time in any way. These directions assume you are running a Duet 3 mini ethernet main board and a Duet3 3HC expansion board, but other options will work too.
2. A [lab automation bed plate](https://github.com/machineagency/science-jubilee/tree/main/tool_library/bed_plate).
3. Hardware to run the color mixing demo. This includes an [Opentrons pipette tool](https://github.com/machineagency/science-jubilee/tree/main/tool_library/OT2_pipette) or other liquid handling tool as well as a downward-facing camera such as the [webcamera tool](https://github.com/machineagency/science-jubilee/tree/main/tool_library/webcamera).
4. An ethernet cable and means to plug it into your computer. Modern laptops will probably require and adapter.

### Software:

1. A computer with python installed, preferably via a conda environment
2. A science-jubilee duet configuration fileset.

### Tools:

1. A set of precision screwdrivers with hex and torx bits. We like the [Mako driver kit](https://www.ifixit.com/products/mako-driver-kit-64-precision-bits) from iFixit.
2. A set of metric hex L keys
3. #2 phillips screwdriver
4. Flush-cut clippers for zip ties
5. Most tool builds will require parts to be 3D printed on a filament printer. You will not need this for the motion platform build if you buy the full kit.
6. Most tool builds will also require making electrical connections through soldering and crimping. You will not need to do this for the motion platform build if you buy the full kit.

## 0. Things to be aware of if you are new to motion platforms

Most of the hardware involved in Jubilee is pretty resilient and can handle a few mistakes in assembly and operation. However, there are some guidelines to follow to keep you and your Jubilee safe:

1. Mind the mains AC terminals on the power supply (and the 24V as well). The Jubilee power supply requires you to make connections to your mains AC power at either 120 or 240V. This is dangerous and could kill you. Don't touch or modify power connections with the machine plugged in. There are printable terminal guard designs for the power supply we reccomend printing and installing, such as [this one](https://www.printables.com/model/329847-lrs-350-24-terminal-cover-voron-edition).

2. Don't plug/unplug stepper motor drivers with the Duet board powered on. This will likely damage your stepper drivers and fry your $$ board. Its good practice not to plug/unplug anything else with the board on, but definetley don't do it for stepper connectors.

3. Mind the belts and moving parts while the machine is in motion.

## 1. Assemble and configure the motion platform

Estimated time: 8 hours - 5 working days

### Hardware assembly

Find more details on building a science jubilee in our docs here:

This is a time consuming process, but it is well worth investing this time as this gets you familiar with the platform. Once you build it, you can understand issues and fix them. New developers in our research group are handed a partially disassembled Jubilee as their first task during the onboarding process. The build process is well documented on the [Jubilee3D wiki](https://jubilee3d.com/index.php?title=Assembly_Instructions). Most of the content for science-jubilee assumes you have a working motion platform and doesn't cover this step.

### Wiring

We have a wiring [quickstart diagram](https://github.com/machineagency/science-jubilee/blob/main/docs/pdfs/jubilee_wiring_colormix.pdf) to wire the boards for our 'default' lab automation configuration. Ignore the connections for the pipette and camera for now. This wiring setup is based off of the [duet3 mini wiring diagram](https://raw.githubusercontent.com/machineagency/jubilee/main/frame/assembly_instructions/wiring/duet3_mini/duet3_mini_frame_wiring.png) from the Jubilee wiki, but may differ slightly.

### Board provisioning and initial connection

You will need to set up configuration files on the duet board to connect to it. First, you will need a bootable microSD card for your Duet. It probably came with a pre-configured SD card in the box. If not, follow the directions at [https://docs.duet3d.com/User_manual/RepRapFirmware/SD_card](https://docs.duet3d.com/User_manual/RepRapFirmware/SD_card) to set one up from scratch.

Setting up g-code configuration files for Jubilee takes a fair amount of sorcery and dark magic. If possible, We recommend starting from our functional configuration file and modifying it to fit your needs. This config hasn't been shared yet. In the meantime DM one of us to get it.

#TODO Put these in a smart place and link here

You will also need to set up your computer's network settings to access Jubilee over a direct ethernet connection. There is a great [write-up](https://jubilee3d.com/index.php?title=Connecting_to_Jubilee) of this process on the Jubilee wiki.

If you have done everything correctly, now you are ready to connect to the machine and home it for the first time! Open a web browser and enter the ip address you assigned Jubilee. In our config this is `192.168.1.2`. You should be connected to the Duet Web Control interface. This is a GUI interface for controlling the Duet boards on Jubilee. It is useful for editing configuration files on the Duet board, making manual machine movements, debugging, and incident recovery.

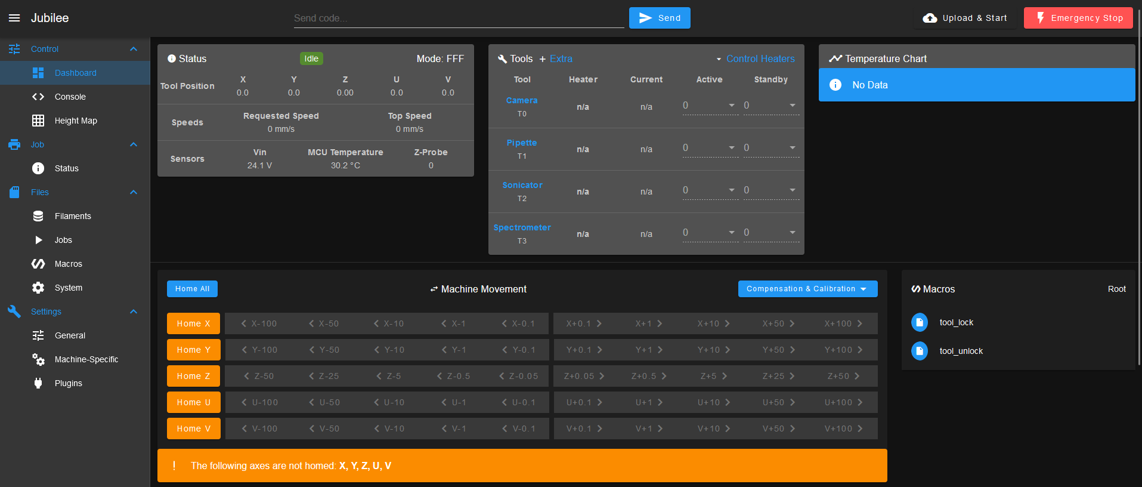
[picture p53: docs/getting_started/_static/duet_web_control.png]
```{figure} _static/duet_web_control.png

Screenshot of duet web control dashboard.
```

Now, you're ready to home the machine for the first time! Homing is a process the motion platform goes through to figure out where it is in space and make sure everything works. During the homing procedure, the machine will move each axis to it's 0 position (see [Jubilee coordinate system primer](primer.md)). You will need to home the machine every time you power it on. Before you proceed, make sure the bed is clear of everything, including the lab automation deck plate. To home the machine from the Duet Web Control interface, click the blue 'home all' button. The first time you home a new machine, expect something to go wrong. Watch the process carefully and keep a finger over the power switch if something goes wrong. There should be no crashing, shuddering, or grinding during this process.

#### First-line troubleshooting

- The duet board does not power on when you turn on the power switch, and you checked that the outlet you are using works
    - There are some fuses that go into the power socket on the machine, where you plug the cable in
    - Double check your wiring connections from the power supply to the duet boards

- An axis does not move during homing
    - Check that the stepper motor is wired correctly, ie that the 4 wires are in the correct order at both terminals (order will depend on your stepper motor and the driver on the duet)
    - Check that the axis is configured correctly in the duet config. Is the connector plugged in where the config says it is supposed to be?

- An axis moves while homing, but the motors do not stop when it hits it's endstop limit switch/ '0' point resulting in a 'crash' and grinding noise.
    - Check that your limit switch is functioning:
        1. Make sure it is plugged in to the I/O port that the config file is expecting for that axis
        2. If the port is correct, check that limit switch is funtional with a multimeter on the continuity setting. The switch/circuit should be closed when the switch is not pressed and open when the switch is pressed.

- The Z-axis goes through it's probing process, then makes a correction that worsens the bed leveling
    - Check that the Z left, right, and back motor connections are not mixed up between the config.g file and the physical connections

## 2. Build and install the tools you will be using

For this tutorial, we need an [OT2 Pipette Tool](../building/) and [Webcamera](https://github.com/machineagency/science-jubilee/tree/main/tool_library/webcamera) tool.

Tool build documentation is a little scattered currently, so you may have to look in various places to get the information you need.

### Building the pipette

Follow the [OT2 Pipette tool documentation](../building/pipette_tool.md) for the pipette build guide.

### Building the camera tool

This tutorial uses the Webcamera tool. This is a raspberry pi camera tool that is set up to serve images through an HTTP endpoint, which allows you to run the main logic of your experiment on a system that is not a raspberry pi. Follow the [documentation](https://github.com/machineagency/science-jubilee/tree/main/tool_library/webcamera) to build the tool.

### Setting tool parking post positions and offsets

After you have completed your tool assembly, you will need to set parking post positions and tool offsets. Parking post positions tell the Jubilee system where the parking posts for the tool are so it can be reliably picked up and parked. Tool offsets calibrate the positioning of the 'active point' of the tool. This allows each tool to move to the same place on the deck when we tell it to go to the same XYZ position as other tools. For the camera, the 'active point' is the center of the field of view, and for the OT2 Pipette tool it is the pipette tip.

1. Follow the [parking post position procedure](../building/parking_posts.md) to set the tool parking post positions for each tool you are using.

:::{warning}
Make sure to drop the bed z height so that the tool will clear the bed when picked up. This will not happen automatically becuase you have not set the tool offsets yet!
:::
2. There are directions on the Jubilee wiki for [setting tool offsets](https://jubilee3d.com/index.php?title=Setting_Tool_Offsets). They provide a good overview of the procedure, but assume you are using a USB microscope to align the tools. I like to use the following, simpler procedure:
    - Place a piece of masking/label tape on the deck and draw an X on it with a fine point sharpie or other fine pen
    - Position the z probe limit switch of the tool carriage over the "X" using the duet web interface jog controls
    - Write down the XYZ coordinates of the X
    - For each tool:
        - Pick up the tool
        - Position it so that the 'active point' is located over the X as precisely as you can
        - Write down the position of the tool
        - Subtract the coordinates you wrote down for the z probe switch above from the position of the tool. This is your tool offset
        - Edit the tool offset in /sys/toffsets.g
        - Load the new tool offset with the gcode command `M98 P'toffsets.g`. The current tool position should update to match the z-probe position you wrote down

## 3. Install and calibrate the lab automation deck plate

 The lab automation deck plate allows you to position labware on the Jubilee deck. It consists of a laser-cut delrin (plastic) mask that mounts to the Jubilee aluminum bed plate using either 3D printed clasps or direct screws, depending on the version. Once the lab automation deck plate is physically mounted, you will need to change the machine configuration files so that the z-axis homing probe pattern accounts for the openings in the delrin, and perform a calibration procedure to use the deck in science-jubilee.

 1. Build the deck plate. Directions can be found [here](../building/lab_automation_deck.md)
 2. Verify that you followed the directions to update the machine config files in the docs linked in step 1.
 3. Create a calibration file for your new deck plate, following the procedure linked [here](./deck_guide.md). Note you need properly set up tools with tools offsets configured before you can do this.

# 4. Control the tools with science-jubilee

Learn how to use the tools you set up by exploring their respective tool operation guides:

TODO: Write up operation guides for pipette and web camera

To use smaller labware like tipracks and 96 well plates, you probably need to perform labware-specific calibrations for each piece of labware in each deck slot. See the [procedure](./deck_guide.md#Labware-Calibration) for this.

# 5. Provision for and run the color mixing demonstration notebook

Now that you have a fully functioning Jubilee with tools attached and calibrated, you are ready to run an experiment! We will start with the color mixing demonstration. See the [color mixing demo getting started guide](./color_mixing_setup.md) for more details on this experiment.

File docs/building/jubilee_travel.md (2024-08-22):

---
title: Notes on traveling with Jubilee
---

(jubilee-travel)=
# Traveling with Jubilee

Updated August 21 2024

We have traveled internationally from the US to Mexico, Canada, and the EU with our Jubilee experimental automation platform. These are some lessons learned and best practices we have settled on. This is written from the perspective of traveling with a Jubilee system, but many of these considerations apply to any experiment automation equipment. This write-up is US-centric, but the ATA Carnet discussion is applicable internationally and the rest of the information should raise considerations for travel from other countries.

## Export Control

You should get your travel plans cleared by your institutions export control office. US export controls are intended to prevent the export of technologies related to weapons development. It is possible that these regulations will prevent export of lab automation equipment. With Jubilee, we avoided any issues with these regulations because the entire platform is open source, with build instructions and software freely available online.

## Customs

In the eyes of Customs, lab automation equipment is ‘commercial merchandise’ if it is used for demonstration/trade show purposes (e.x., demonstration at Accelerate conference) or experiments (e.x, travel to a beamline). This means that import duties could be levied on the equipment. There are a few ways to handle this. The best option will depend on how the equipment is packaged and how much it is worth. Simply not declaring the item can be risky. You could be theoretically be required to pay import duties on the equipment both when importing it into the country you are visiting and when re-importing it to the US. If the item is large enough to be packed in its own case, especially if the case is a pelican or flight case, you are likely to be questioned about it.
1.	Declare the item and pay the import duty and possibly taxes (sales, VAT, etc. depending on the locale). This can be a viable approach for low-value items and one-off travel. Make sure to do your research so you know what duty rate to expect, and come prepared with a well-documented valuation of the item so to avoid arbitrary valuations from customs agents. You should also fill out a [US CBP form 4455 certificate of registration](https://www.cbp.gov/document/forms/form-4455-certificate-registration) for your items. This will allow you to re-import to the items to the US without paying duties. To use this form, you will out the items you will be traveling with and present the form along with the items to a US customs officer before leaving the US. When you return to the US, present the form again. Note this does not help you avoid any duties with foreign customs.
2.	Obtain and use an ATA Carnet. This is the 'right' way to do temporary importation. An ATA Carnet is a 'passport for merchandise'. It is an internationally recognized customs document that allows you to temporarily import equipment without paying duties or taxes. To use an ATA carnet, you first purchase one from one of the authorized vendors in the US in advance of your trip. When purchasing, you will provide a list of all the items you plan to travel with including serial numbers and values. To use the carnet, you present it along with your items to customs each time the item is imported or exported. For a typical international trip, this means you get a stamp before you leave the US, on arrival at your destination country, before you leave your destination country, and upon return to the US. This does add a significant amount of time and logistics overhead to travel so plan accordingly. The cost of an ATA carnet starts at around $500, and the document is valid for one year. The price depends on the value of the listed goods. We use [Boomerang Carnets](https://www.atacarnet.com/) and would recommend them as they have excellent customer support.

Here are some specific tips for traveling with an ATA Carnet:
- When flying, you need to have your items inspected and Carnet stamped before they are checked for the first flight of your trip. Generally, you will tell the airline ticket agent that you need a Carnet stamped when you are checking in. They will call a customs officer, who will stamp your carnet at the check-in counter. Leave enough time for this when scheduling airport arrivals. Call the customs office ahead of time to confirm their hours and this procedure for calling an officer.
- It is recommended that you make the first flight of your trip an international flight if feasible. Technically, Carnets should be stamped at the port of departure, which is the last US airport the items transit through. A customs officer who wants to make your life miserable could require you to get the carnet stamped at your port of departure. If you have a connecting flight within the US and are checking your equipment, this would require you to claim your baggage at your connection, get your carnet stamped, re-check your bags, and clear security again – basically impossible on most connections. If a direct international departure isn't feasible, reasonable customs officers should be able to stamp you out at the first flight of your trip. Consider calling customs at your airport to make sure this will work before planning your trip.
- When you are having your carnet stamped on arrival at your foreign destination, ask  about procedures for finding a customs officer and getting your carnet stamped on departure.
- There are 2 ways to fill out the itemized list of equipment on the carnet: individually itemizing every component, and the ‘single line item’ approach. For custom, integrated equipment, it is possible to list the entire set of equipment as one line item with a made up serial number. For example, ‘Automated synthesis machine, serial number 1’. Then label each individual component in the shipment as ‘Integral component of automated synthesis machine, SN#1’ or something similar. We have known researchers who have successfully used this approach. It does give flexibility to add or modify equipment without re-printing your carnet. The itemized approach, on the other hand, requires you to pre-plan and list every component you will be traveling with. This can be more restrictive. However, the itemized list is what customs officers are used to seeing so it may raise fewer questions. In our experience, customs officers will ask to see one item with a serial number to match to the list. I make sure to list at least one serial number, even if it is for something trivial like an ethernet switch.

# Packing and transport

A major advantage of the Jubilee platform is it’s packability. With reasonable effort, Jubilee can be packed as airline checked baggage, greatly simplifying logistics compared to systems that require crating and shipping. Here is how we fly with our Jubilee and associated equipment:
-	We pack Jubilee by collapsing the Z axis. We replace all the vertical extrusion components with the 80mm extrusion pieces used to square the frame during assembly which reduces the total height including feet to ~10". We cut our 80mm extrusions down even further to save more space.
-	A major concern in packing for flying is weight. Most airlines have a 50 pound weight limit before (expensive) overweight fees kick in. Jubilee with tools is generally around 40 pounds. We generally pack Jubilee into two bags: One for the main motion platform top and bottom frame, and one for the Z axis components, bed, Jubilee tools, hand tools, spares, and other components. Paying for a second checked bag is generally much cheaper than paying overweight fees.
-	You will need some sort of case for Jubilee. We have tried a pelican case and a conventional suitcase before settling on a custom flight case. Finding a pelican case large enough to fit the Jubilee frame requires using a bulky, airline-oversized, and heavy case. A regular suitcase, on the other hand, provides little protection. We had a custom flight case made to fit Jubilee. It weighs 20 pounds, has an aluminum frame, and fits a collapsed Jubilee perfectly while staying within airline size requirements. We had ours made at [Custom Crating](https://customcrating.com/) in Seattle. Pricing is in line with an appropriately sized Pelican case. As a second bag, we use a regular suitcase as we are less concerned about protection for the non-frame components.
-	Pelican cases and flight cases will be treated as oversize baggage, even if they are not. This seems to greatly increase the risk of your bag being left behind at your departure airport. Given this, we fly with AirTags in our cases to assist with tracking down a lost Jubilee. It is also advisable to give yourself some extra time between your arrival and any activities that require a Jubilee to account for this increase risk of baggage issues.



_[[Source](https://jubilee3d.com/index.php?title=Specs#/media/File:Jubilee_overall_dimensions.png)]. Dimensions in mm. Equivalent to: 23.78" x 18.74" x 21.97". B2: Top-view. A2: side view._

## Products

### Jubilee in assembled state (untested)
1. [Pelican 0370](https://www.pelican.com/us/en/product/cases/cube-case/protector/0370/) (tight tolerance in longest dimension, likely to the point of needing to remove the Pelican foam, heavy)
2. [Outdoor Square Cushion/Cover Storage Bag](https://www.amazon.com/gp/product/B0BC8PTRHR/) (ample space, but requires significant custom padding/foam and at least one heavy duty cardboard insert at the bottom)
3. Custom ATA case 23" W x 28" D x 26" H (including foam). Standard Duty 3/8" Plywood. 2" foam all sides. (needs to be verified). E.g., [through Roadcases](https://www.roadcases.com/custom-quote-pull-along-case/) or a local ATA manufacturer. Note that lead times can be long (weeks).
4. Corrugated box [28" x 28" x 28"](https://www.uline.com/Product/Detail/S-4433/Corrugated-Boxes-200-Test/28-x-28-x-28-Corrugated-Boxes) (no hand holes)

Perhaps also:
1. Corrugated box [26" x 26" x 26"](https://www.uline.com/Product/Detail/S-4190/Corrugated-Boxes-200-Test/26-x-26-x-26-Corrugated-Boxes) (no hand holes)
2. Double-walled corrugated box [25" x 25" x 25"](https://www.uline.com/Product/Detail/S-22118/Heavy-Duty-Boxes/25-x-25-x-25-275-lb-Double-Wall-Corrugated-Boxes) (no hand holes)
3. [Triple-wall cardboard 24" x 24" x 24"](https://www.uline.com/Product/Detail/S-13331/Bulk-Cargo/24-x-24-x-24-1100-lb-Triple-Wall-Boxes) (no hand holes)
4. [Triple-wall cardboard 30" x 30" x 30"](https://www.uline.com/Product/Detail/S-11301/Bulk-Cargo/30-x-30-x-30-1100-lb-Triple-Wall-Boxes) (no hand holes)
5. Corrugated Boxes with hand holes [24" x 24" x 24"](https://www.uline.com/Product/Detail/S-14213/Moving-Boxes/24-x-24-x-24-Corrugated-Boxes-with-Hand-Holes)

### Jubilee in height-reduced state
1. [Pelican 1640](https://www.pelican.com/us/en/product/cases/transport-case/protector/1640/)
2. Custom ATA case 23" W x 28" D x 14" H (including foam). Standard Duty 3/8" Plywood. 2" foam all sides. (needs to be verified). E.g., [through Roadcases](https://www.roadcases.com/custom-quote-pull-along-case/) or a local ATA manufacturer. Note that lead times can be long (weeks).

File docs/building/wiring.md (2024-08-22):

---
title: Wiring Jubilee
---

(default-wiring)=
# Default wiring guide

This is our recommended default wiring for new Jubilee builds. Start here unless you know you need something different.

#TODO: Bring in content of [wiring guide PDF](https://github.com/machineagency/science-jubilee/blob/main/docs/pdfs/jubilee_wiring_colormix.pdf)

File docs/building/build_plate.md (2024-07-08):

---
title: Magnetic Build Plate Assembly
---

(build_plate)=
# Magnetic Build Plate Assembly

## Video
_Video editing in progress!_

## Build Plate Assembly
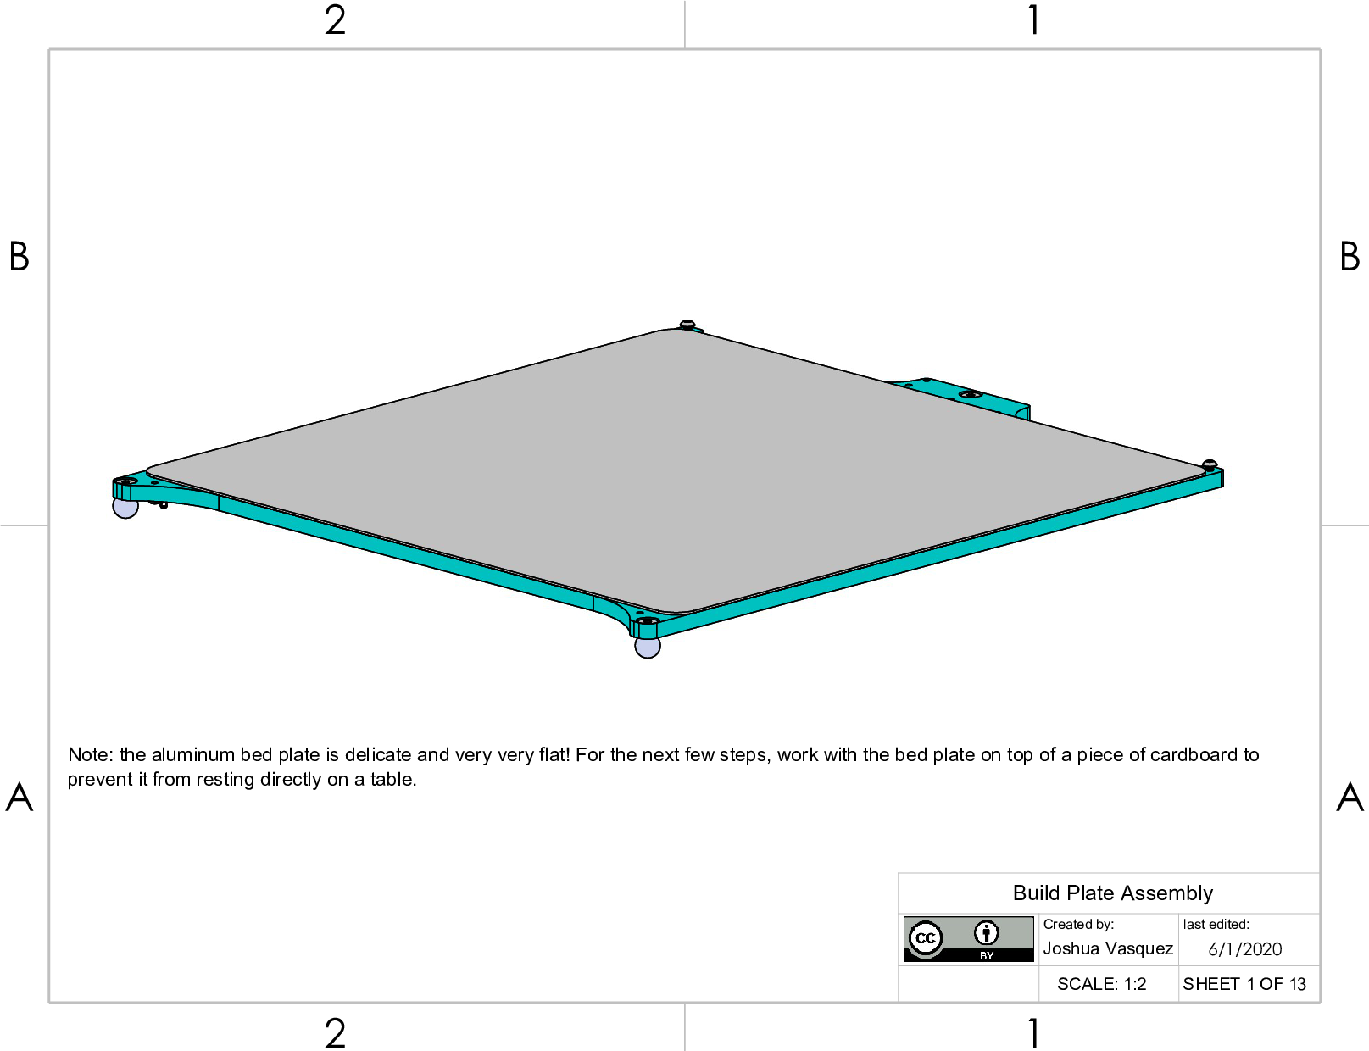
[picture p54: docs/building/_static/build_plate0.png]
Page1


## Magnetic Sheet Application
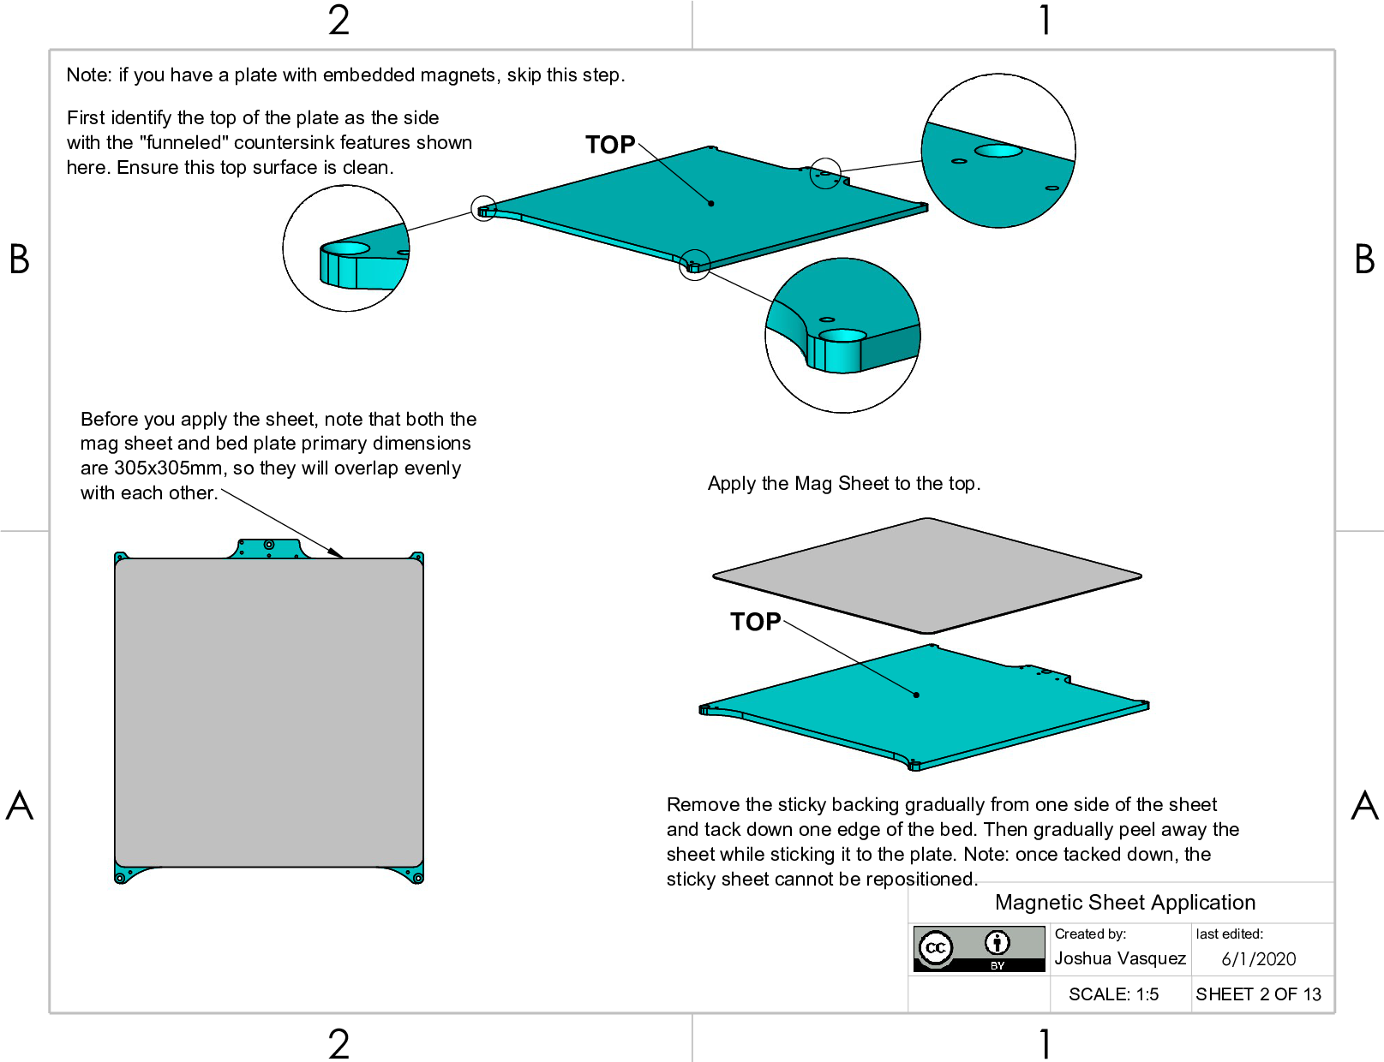
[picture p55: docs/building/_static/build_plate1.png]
Page2


## Grounding Wire Fabrication
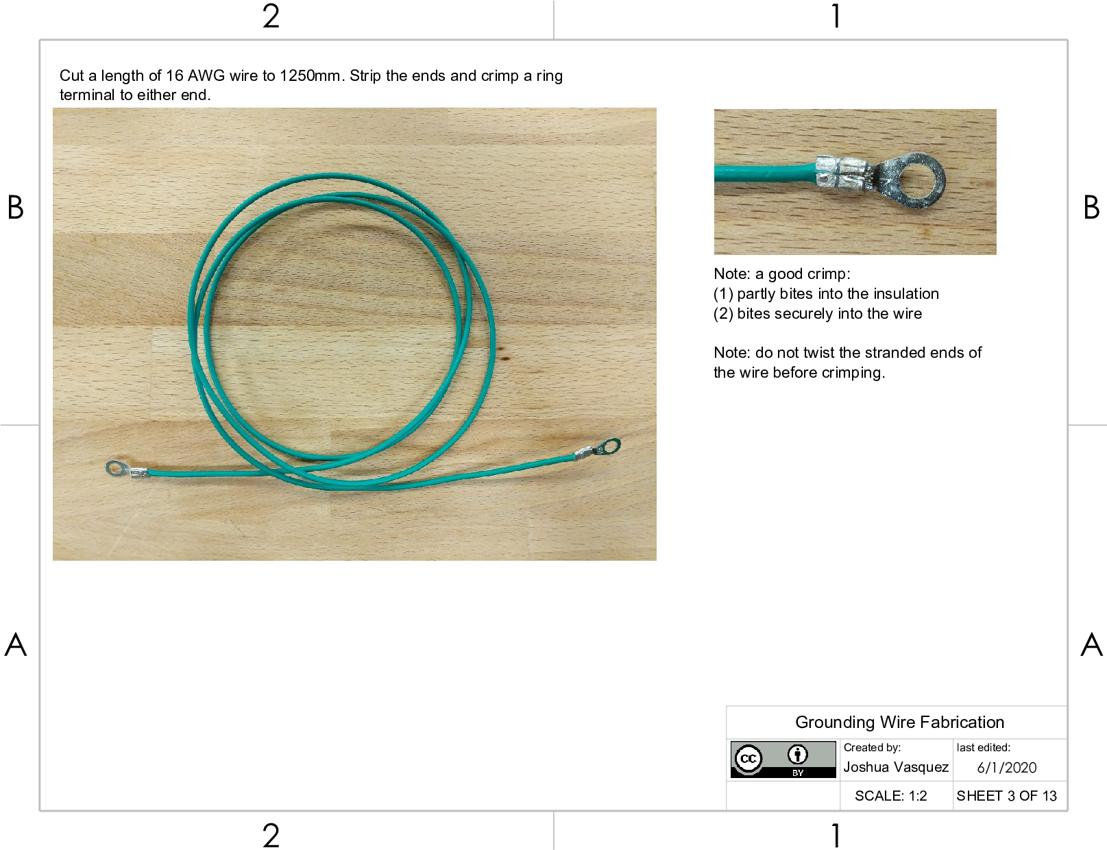
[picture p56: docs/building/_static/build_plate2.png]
Page3


## Kinematic Ball Installation
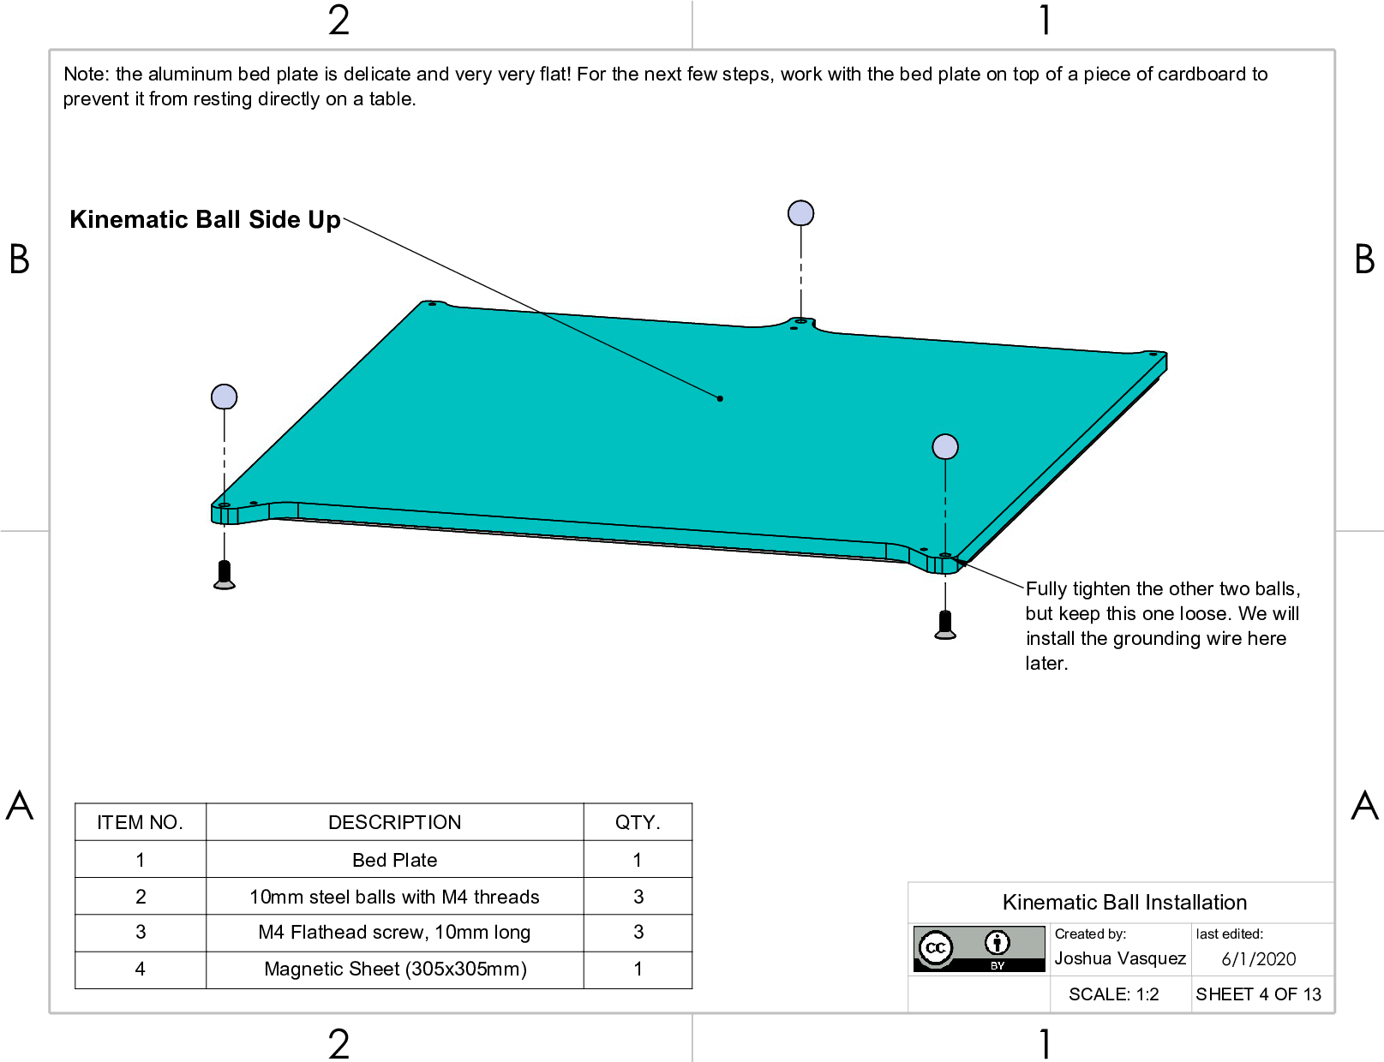
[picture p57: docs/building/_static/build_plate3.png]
Page4


## Bed Retaining Screw Installation
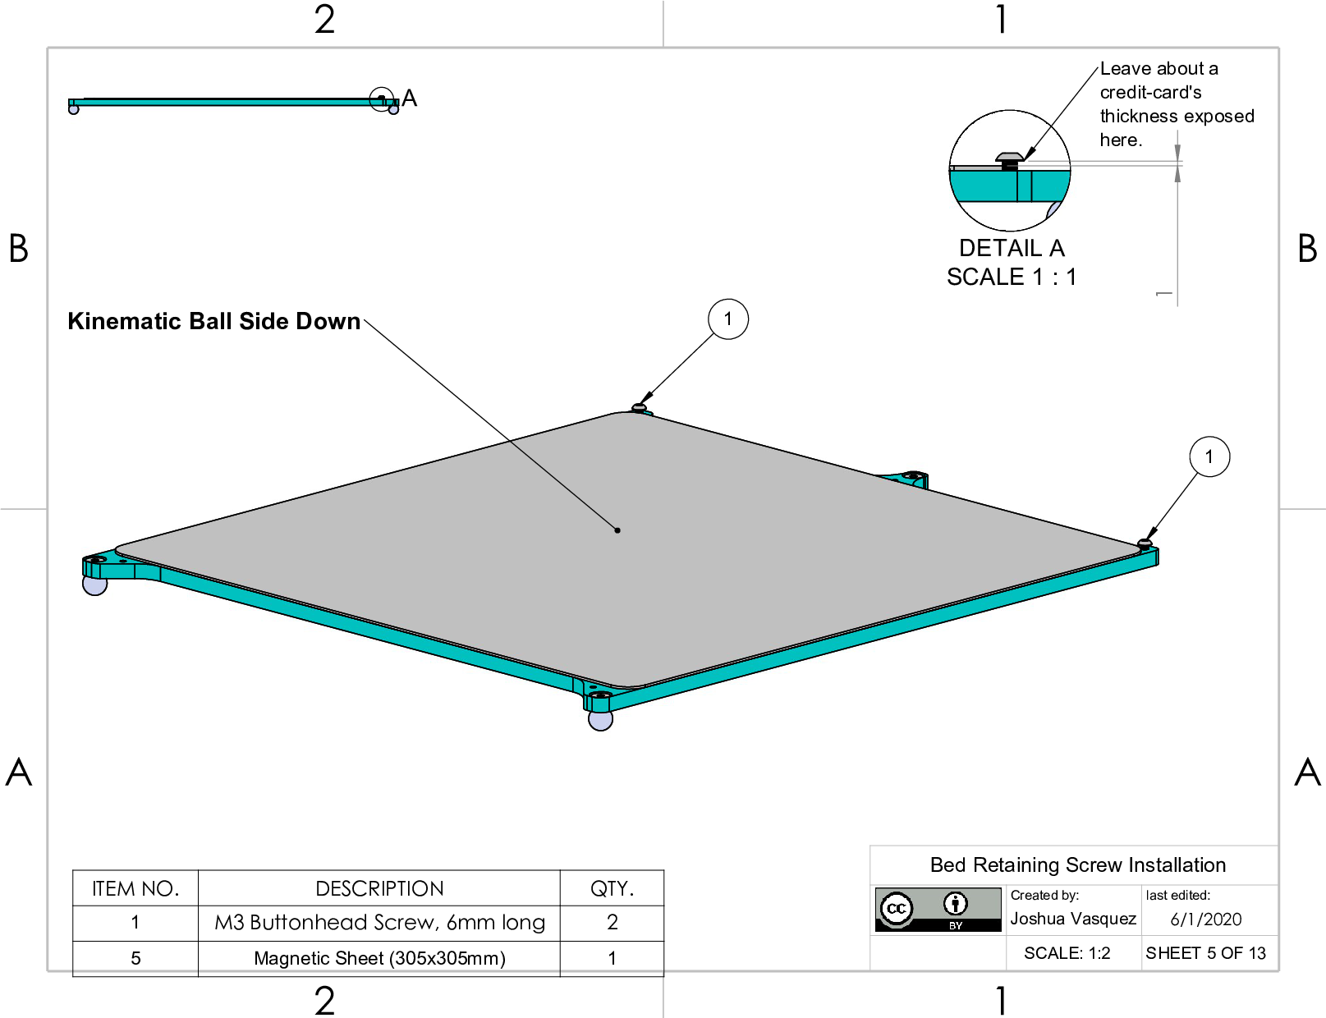
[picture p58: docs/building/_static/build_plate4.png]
Page5


## Thermistor Wiring
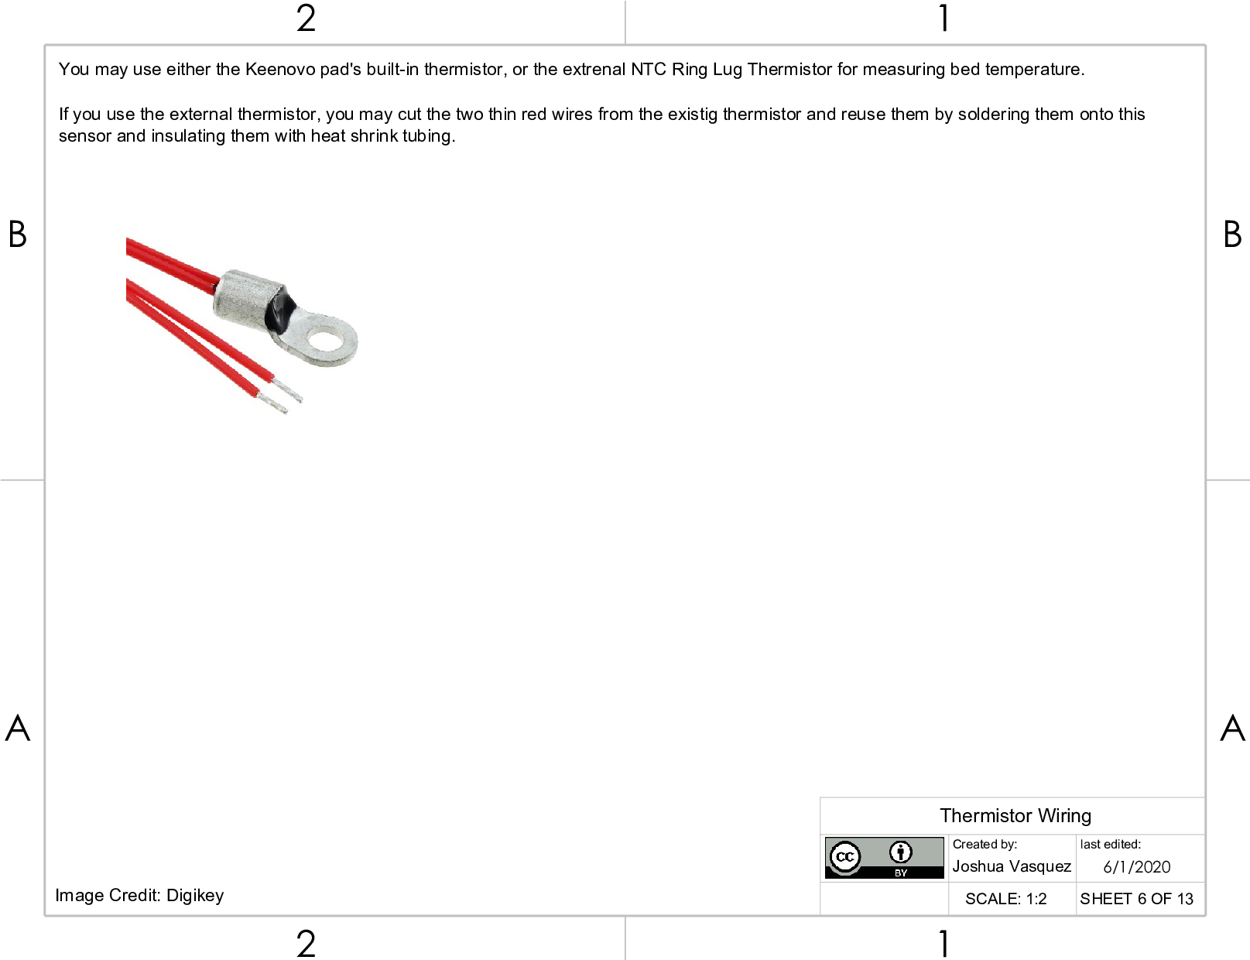
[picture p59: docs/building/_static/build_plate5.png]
Page6


## Spring Anchor Creation 1/2
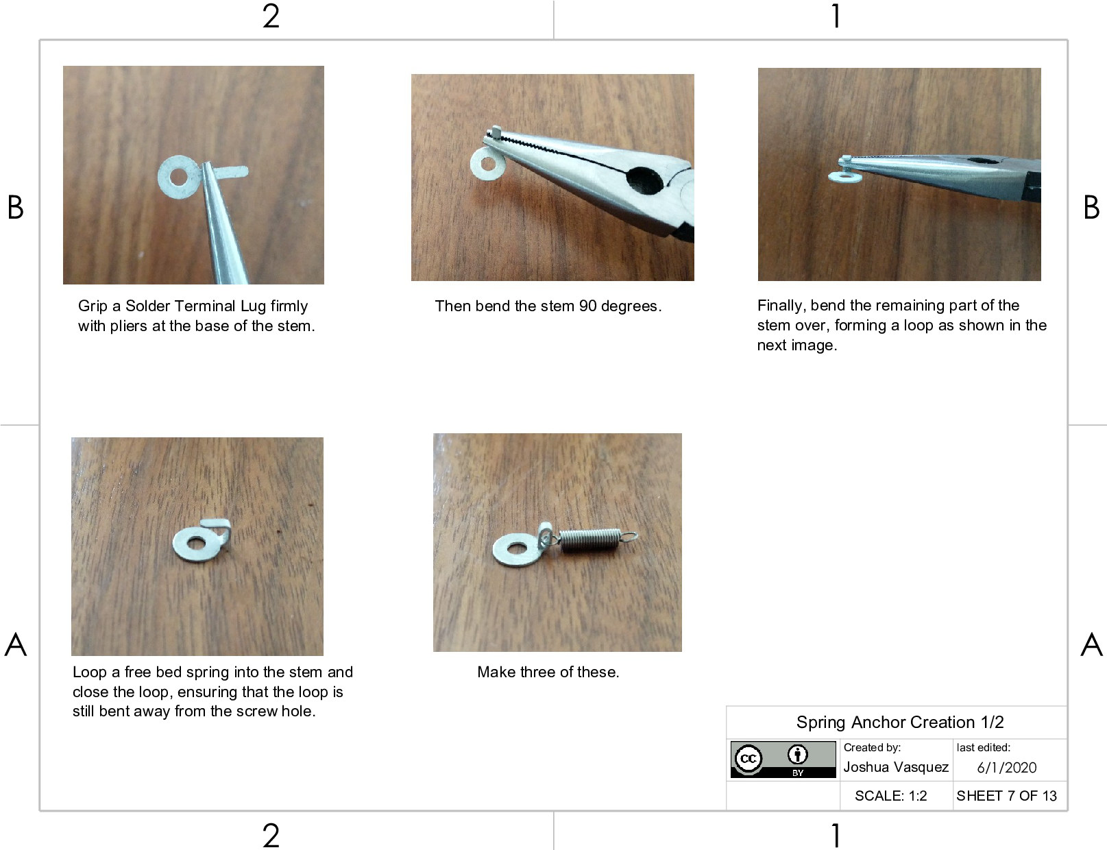
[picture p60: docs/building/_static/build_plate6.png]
Page7


## Spring Anchor Creation 2/2
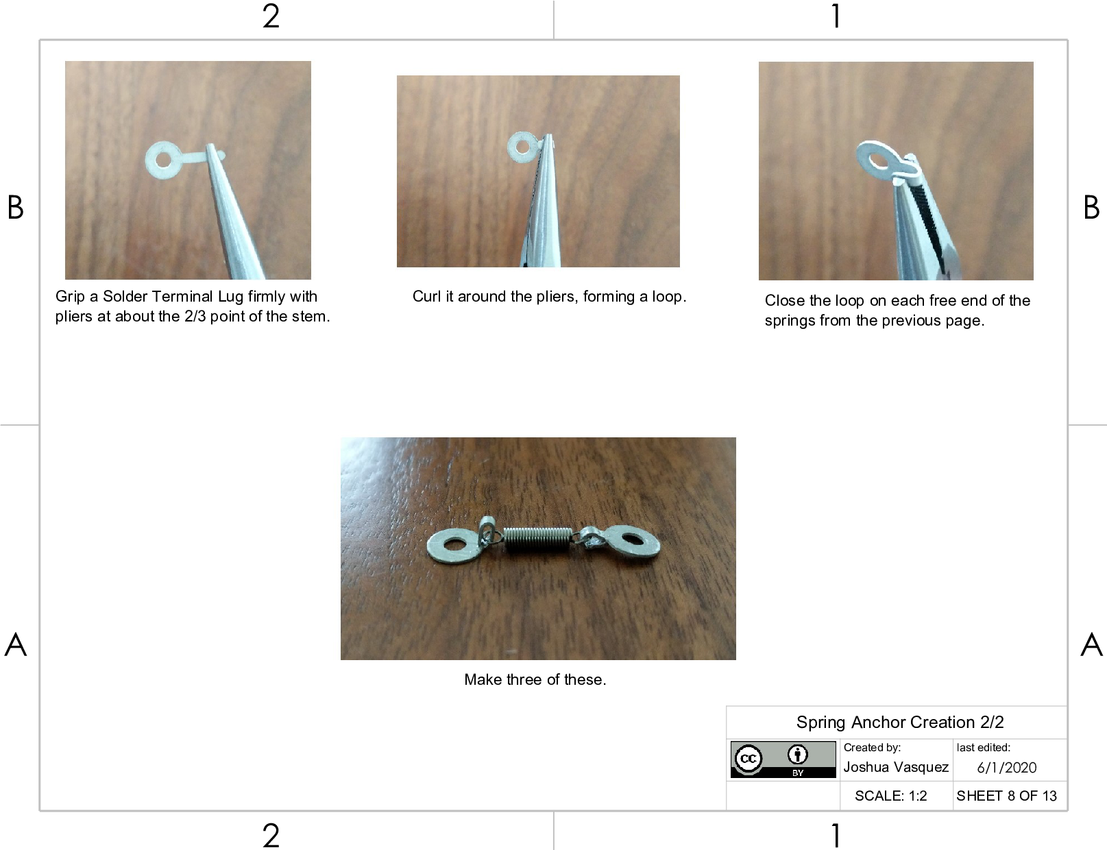
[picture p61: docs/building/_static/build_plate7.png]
Page8


## Spring Anchor Installation
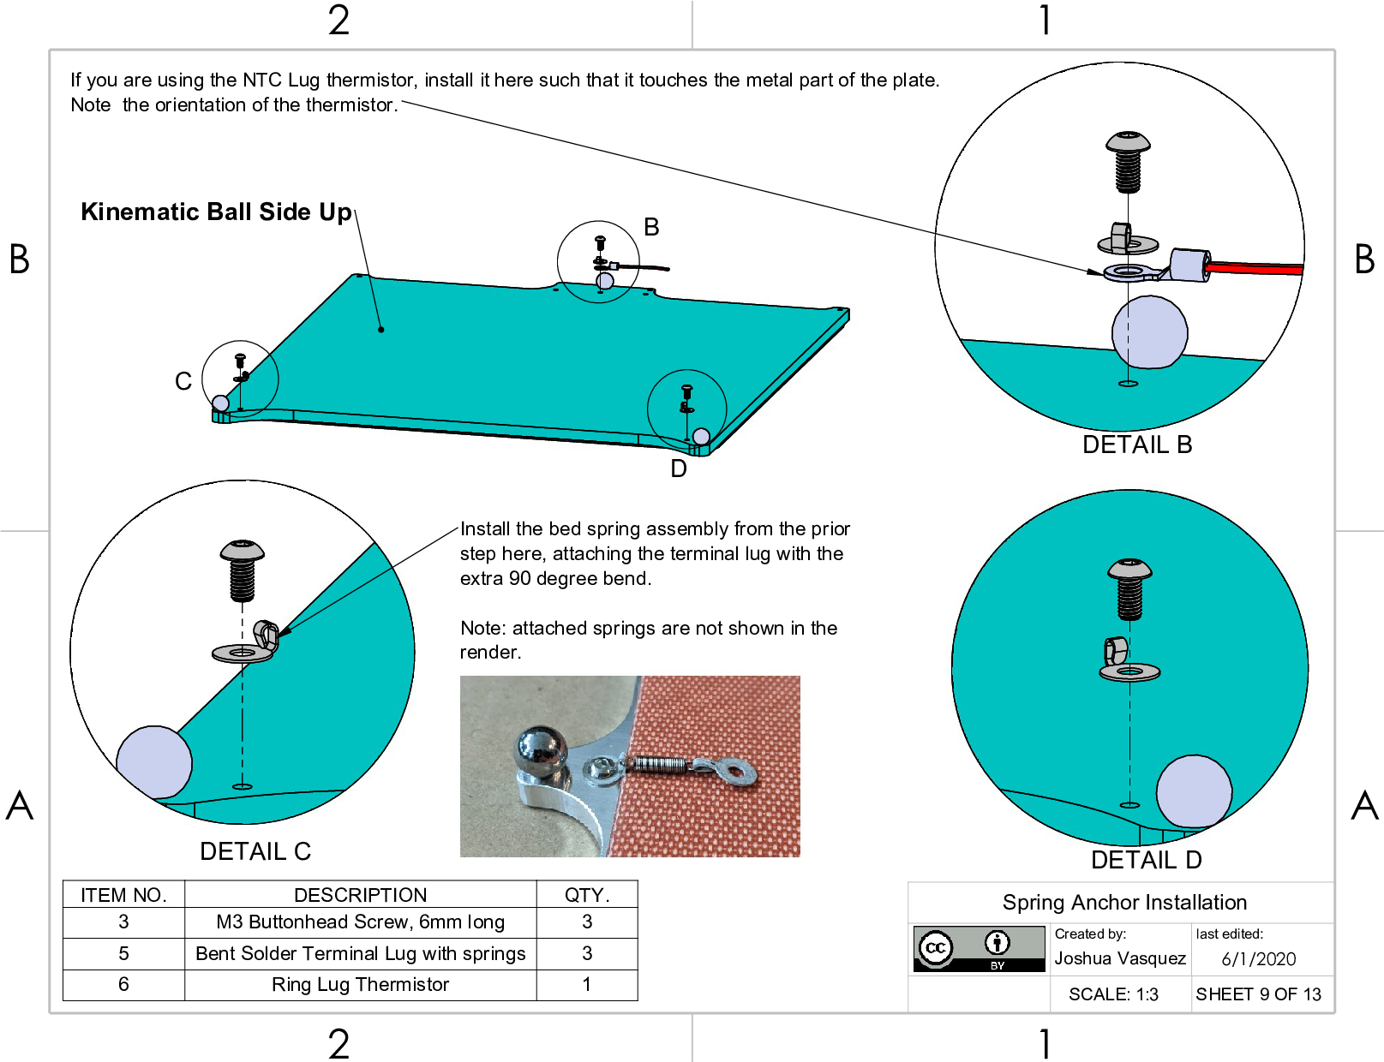
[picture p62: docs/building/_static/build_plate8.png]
Page9


## Heated Pad Wire Management 1/2
Page10

## Heated Pad Wire Management 2/2
Page11

## Heated Pad Installation
Page12

## Grounding Wire Installation
Page13

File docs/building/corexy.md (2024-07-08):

---
title: CoreXY Frame Assembly
---

(corexy)=
# CoreXY Frame Assembly

## Video
_Video editing in progress!_

## XY Frame Assembly
Page1

## Upper Bracket Alignment 1
Page2

## Frame Conveniences
Page3

## Carriage Center Installation
Page4

## Y Rail Assembly
Page5

## Plate Installation 1/2
Page6

## Y Rail Installation
Page7

## Corner Bracket T Nut Install
Page8

## Plate Installation 2/2
Page9

## Crossbar Installation
Page10

## Carriage Back Installation
Page11

## Front Carriage Assembly
Page12

## Remote Elastic Lock Installation
Page13

## Twist Lock Orientation Check
Page14

## Lock Actuator Tension Check
Page15

## Crossbar Squaring
Page16

## Belt Installation
Page17

## Belt Tensioning
Page18

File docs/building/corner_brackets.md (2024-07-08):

---
title: Inside Corner Bracket Prep
---

(corner-brackets)=
# Inside Corner Bracket Prep

## Video
```{youtube} TstW4cVs-m8
```

## Part Prep
Page1

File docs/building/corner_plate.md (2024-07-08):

---
title: Double Pulley Corner Plate Assembly
---

(corner-plate)=
# Double Pulley Corner Plate Assembly

## Video
```{youtube} YDzGue4y-to
```

## Double Pulley Corner Plate Assembly
Page1

## Left Corner Generic Pulley Assembly
Page2

## Left Corner Gates Pulley Assembly
Page3

## Left Corner Pulley Assembly
Page4

## Right Corner Generic Pulley Assembly
Page5

## Right Corner Gates Pulley Assembly
Page6

## Right Corner Pulley Assembly
Page7

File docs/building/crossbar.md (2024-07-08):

---
title: Aluminum Crossbar Assembly
---

(crossbar)=
# Aluminum Crossbar Assembly

## Video
_Video editing in progress!_

## 041 Aluminum Crossbar Assembly
Page1

## Left Crossbar Generic Pulley Assembly
Page2

## Left Crossbar Gates Pulley Assembly
Page3

## Left Crossbar Pulley Installation
Page4

## Right Crossbar Generic Pulley Assembly
Page5

## Right Crossbar Gates Pulley Assembly
Page6

## Right Crossbar Pulley Installation
Page7

## Rail Installation
Page8

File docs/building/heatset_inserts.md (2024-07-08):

---
title: Heatset Insert Installation
---

(heatset-inserts)=
# Heatset Insert Installation

## Video
Heat set inserts start at 2:17 of this video!
```{youtube} TstW4cVs-m8
```

## Parts with Heat Set Inserts
Page1

## Part Inspection
Page2

## The Plate Press Technique Overview
Page3

## M4 Insert Installations
Page4

## M3 Insert Installations
Page5

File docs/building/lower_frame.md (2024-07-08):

---
title: Lower Frame Assembly
---

(lower-frame)=
# Lower Frame Assembly

## Video
_Video editing in progress!_

## Lower Frame Assembly
Page1

## Corner Foot Installation
Page2

## Z Motor Thrust Coupling Assembly
Page3

## Back Z Motor Plate Assembly
Page4

## Front Left Z Plate Assembly
Page5

## Front Right Z Plate Assembly
Page6

## Internal Extrusion Alignment
Page7

## Z Plate Locating
Page8

## Z Plate Tightening
Page9

## Inside Corner Bracket Installation
Page10

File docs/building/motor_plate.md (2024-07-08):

---
title: Aluminum Motor Plate Assembly
---

(motor-plate)=
# Aluminum Motor Plate Assembly

## Video
_Video editing in progress!_

## Machined Motor Plate Assembly
Page1

## Spacer Assembly
Page2

## Drive Pulley Assembly
Page3

## Left Motor Plate Assembly 1/4
Page4

## Left Motor Plate Assembly 2/4
Page5

## Left Motor Plate Assembly 3/4
Page6

## Left Motor Plate Assembly 4/4
Page7

## Right Motor Plate Assembly 1/4
Page8

## Right Motor Plate Assembly 2/4
Page9

## Right Motor Plate Assembly 3/4
Page10

## Right Motor Plate Assembly 4/4
Page11

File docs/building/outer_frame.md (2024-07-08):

---
title: Outer Frame Assembly and Alignment
---

(outer-frame)=
# Outer Frame Assembly and Alignment

## Video
```{youtube} F9muWrowDzE
```

## Outer Frame Assembly/Alignment
Page1

## Intro
Page2

## Upper Frame Squaring 1/5
Page3

## Upper Frame Squaring 2/5
Page4

## Upper Frame Squaring 3/5
Page5

## Upper Frame Squaring 4/5
Page6

## Upper Frame Squaring 5/5
Page7

## Lower Frame Squaring 1/5
Page8

## Lower Frame Squaring 2/5
Page9

## Lower Frame Squaring 3/5
Page10

## Lower Frame Squaring 4/5
Page11

## Lower Frame Squaring 5/5
Page12

## Stamped T Nut Intro
Page13

## Upper Frame Assembly 1/6
Page14

## Upper Frame Assembly 2/6
Page15

## Upper Frame Assembly 3/6
Page16

## Upper Frame Assembly 4/6
Page17

## Upper Frame Assembly 5/6
Page18

## Upper Frame Assembly 6/6
Page19

## Upper Frame Bracket Loose Assembly
Page20

## Lower Frame Loose Assembly 1/8
Page21

## Lower Frame Loose Assembly 2/8
Page22

## Lower Frame Loose Assembly 3/8
Page23

## Lower Frame Loose Assembly 4/8
Page24

## Lower Frame Loose Assembly 5/8
Page25

## Lower Frame Loose Assembly 6/8
Page26

## Lower Frame Loose Assembly 7/8
Page27

## Outer Frame Loose Assembly 8/8
Page27

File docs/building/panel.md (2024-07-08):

---
title: Duet Electronics Panel Assembly
---

(panel)=
# Duet Electronics Panel Assembly

## Video
_Video editing in progress!_

## Duet 2 Electronics Panel Assembly
Page1

## Duet 2 Standoff Installation
Page2

## Mounting Screw Installation
Page3

## Duet2 and Duex5 Installation
Page4

## SSR Installation
Page5

## PSU Installation
Page6

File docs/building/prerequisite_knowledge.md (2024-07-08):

---
title: Prerequisite Knowledge
---

(prerequisite-knowledge)=
# Prerequisite Knowledge

Here are some useful how-to links, relevant to various assembly steps!

* [Working with Heat-Set Inserts via the ''Plate Press'' Technique](https://hackaday.com/2019/02/28/threading-3d-printed-parts-how-to-use-heat-set-inserts/)
* [Working with Inside Corner Brackets](https://jubilee3d.com/index.php?title=Working_with_Inside_Corner_Brackets)
* [How to crimp Molex Connectors](https://www.youtube.com/watch?v=8jcfD1UW8SE)
* Tip: print this [Fastener Reference Sheet](https://docs.google.com/viewer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) at 100% scale for an easy sanity check.

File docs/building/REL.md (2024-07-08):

---
title: Toolchanger Remote Elastic Lock Assembly
---

(REL)=
# Toolchanger Remote Elastic Lock Assembly

## Video
_Video editing in progress!_

## Remote Elastic Lock Assembly
Page1

## Variants
Page2

## Parts with Inserts
Page3

## Part Prep
Page4

## Base Plate Assembly
Page5

## Floating Half Pulley Assembly
Page6

## Fixed Half Pulley Assembly
Page7

## Wiring
Page8

## Limit Switch Installation
Page9

## Motor Installation
Page10

## Shaft Alignment
Page11

## Pulley and Spring Assembly
Page12

## Fixed Pulley Securing
Page13

## Knob and Cable Management
Page14

## Spring Guide Installation
Page15

## Wire Rope Routing
Page16

## Wire Rope Termination
Page17

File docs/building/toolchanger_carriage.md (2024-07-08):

---
title: Toolchanger Carriage Assembly
---

(toolchanger_carriage)=
# Toolchanger Carriage Assembly

## Video
_Video editing in progress!_

## Toolchanger Carriage Assembly
Page1

## Coupling Plate Assembly
Page2

## Pulley Assembly
Page3

## Twist Lock Assembly
Page4

## Wiring Installation
Page5

## Carriage Back Plate Assembly
Page6

## Carriage Center Assembly
Page7

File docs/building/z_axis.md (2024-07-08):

---
title: Z Axis Assembly
---

(z-axis)=
# Z Axis Assembly

## Video
_Video editing in progress!_

## Z Axis Assembly
Page1

## Lead Screw Nut Installation
Page2

## Front Coupling Plate Assemblies
Page3

## Back Z Lift Assembly
Page4

## Linear Rail Assembly
Page5

## Front Z Tower Assembly
Page6

## Leadscrew Retainer Assembly
Page7

## Screw Preloading
Page8

## Front Z Lift Assemblies
Page9

## Front Z Tower Assemblies
Page10

## Back Z Lift Assembly
Page11

## Back Z Tower Assembly
Page12

## Ooze Control Assembly
Page13

## Power Socket Holder 1/2
Page14

## Power Socket Holder 2/2
Page15

## Z Axis Extrusions
Page16

## Z Axis Extrusion T Nuts
Page17

## Corner Vertical Extrusions
Page18

## Corner Extrusion T Nuts
Page19

## CoreXY Installation 1/2
Page20

## CoreXY Installation 2/2
Page21

## PSU Installation
Page22

## Bed Plate Installation
Page23

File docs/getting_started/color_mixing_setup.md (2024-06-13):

---
title: Color Mixing Demonstration Setup Guide
---

(color-mixing-setup)=
# Color Mixing Demonstration Setup Guide

## Introduction

This guide walks you through running the Pozzo research group's color mixing demonstration. The color mixing demonstration is a basic example of an autonomous experimentation platform or self driving lab. In a color mixing experiment, a system learns how to make a user-selected target color by mixing source primary colors in various ratios. In our implementation, we use diluted acrylic paint as primary source colors. A Bayesian optimization campaign optimizes toward a user-selected target color by varying the volume fraction of each primary color that is added to a sample. Samples are prepared with an OT2 pipette in a 96 well plate, and characterized using a raspberry pi camera.

While this guide is specific to this experiment, many steps detailed here are transferable to other experiments. The related config files and Jupyter notebooks could be used as templates to set up new experiments.

This guide is a work in progress. Contact bgpelkie [at] uw dot edu with questions.

You can find the instructions for running the color mix demo along with the code at [https://github.com/pozzo-research-group/jubilee_pipette_BOdemo](https://github.com/pozzo-research-group/jubilee_pipette_BOdemo)

## Required Equipment

To reproduce this tutorial exactly, you will need the following items. You should be able to substitute similar equipment with similar functionality, for example using a peristaltic pump dispensing tool instead of an OT2 pipette tool.

1. An assembled and provisioned Jubilee motion platform with a calibrated lab automation deck plate
2. An OT2 Pipette tool and webcamera tool on your Jubilee, with tool offsets and tool-specific calibrations completed.
3. Acrylic paint in red, yellow, blue, white, and black. No need for anything fancy here
4. A 96 well plate (~400 uL well volumes)
5. A 12 scintillation vial holder labware, printable from the [Pozzo group labware repo](https://github.com/pozzo-research-group/Automation-Hardware/tree/master/Vial%20Holders/20mlscintillation_12_wellplate_18000ul).
6. Opentrons tiprack, with tips, for your pipette tool
7. 5 20cc scintillation vials for holding paint stocks

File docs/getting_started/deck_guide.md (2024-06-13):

---
title: Lab Automation Deck Tutorial
---

(deck-guide)=
# Lab Automation Deck Tutorial

This guide walks you through the basics of using a lab automation deck in conjunction with labware. It assumes you have a lab automation deck installed on your machine. If you don't have a lab deck installed on your machine, check out the [deck build instructions](../building/lab_automation_deck.md)

The lab automation

## Creating a Deck Definition

The standard lab automation deck consists of 6 slots that accept and [ANSI/SLAS](https://www.slas.org/education/ansi-slas-microplate-standards/) standard microplate, or any piece of labware that adheres to the footprint dimensions of this standard.  (indices 0-5), and a number of optional garbage containers which can be positioned outside of the deck footprint:

```{figure} _static/plate.png
---
scale: 50%
alt: deck layout
---
A lab automation deck holding a 6-, 24-, and 96-well plate as well as a pipette tip rack and petri dish of duckweed. The 3D printed frame off the bed houses a sharps container.
```

```{figure} _static/deck_layout.png
---
scale: 50%
alt: deck layout
---
Orientation of slots on deck and labware in slots.
```

To use the lab automation deck, we need to set the offsets for each of the 6 slots, as well as any off-deck containers, and place the definition in the `decks/deck_definitions/` directory. The preferred method to do so accurately is with a camera tool; the [deck definition calibration notebook](https://github.com/machineagency/science-jubilee/blob/main/src/science_jubilee/calibration/LabAutomationDeckCalibration.ipynb) interactively guides you through this process. If you do not have a camera tool, this can also be done using any other tool that extends into the build volume such that you can accurately align the tool tip to a corner of each slot. Make sure to load the appropriate deck calibration file every time you set up an experiment (#TODO: Add a 'setting up an experiment' page that walks through how to set up with science-jubilee library).

You should not need to re-do the deck calibration often during normal usage. You will need to re-do the calibration if you disassemble the lab automation deck assembly (ie remove the delrin mask from the aluminum bed plate).

## Creating Labware Definitions

Each piece of labware requires a labware definition in `labware/labware_definitions`. This file contains accurate measurements and information about the dimensions, well positions, and more for your labware. Our format is identical to the [OpenTrons labware definitions](https://support.opentrons.com/s/article/What-is-a-labware-definition). If you have used an OpenTrons before, this means you can use any existing labware definitions you have with Jubilee. It also means you can use the Opentrons [Labware Designer](https://labware.opentrons.com/create/) to create custom definitions.

In general, labware is saved in the format `<brand>_<number_of_wells>_<labware_type>_<well_volume>_<extra_identifiers>.json`. For example, a Corning 96 well plate has the name `corning_96_wellplate_360ul_flat.json`; an OpenTrons pipette tip rack is named `opentrons_96_tiprack_300ul.json`. We recommend following this convention for specificity and for sharing experimental workflows.

## Labware Calibration

Due to tolerances in the deck plate, labware, and their interface, you will likely need to perform a manual offset calibration to get good location accuracy. This is mostly the case for smaller labware items like 96 well tipracks and well plates. Do this calibration after you have performed a deck definition calibration (described above) and selected a labware layout for your experiment. This calibration will correct for any translational or rotational deviations from the deck plate calibration.

**Note: This calibration will assume your wells are evenly spaced on your labware. If this is not the case, do not use this calibration. You instead may need to manually set a position for each individual well or adjust your deck definition coordinates**

1. Place your labware in the selected location on the deck plate.
2. Pick up a tool that has had its offsets correctly set. An OT2 pipette tool or other 'probe' tool is preferred for this step
3. Using the Duet Web Control interface jog controls, place the tool over the 'A1' well on the first piece of labware. Align the tool as precisely as you can, then write down the XY coordinates
4. Repeat step 3 for the ("first row, last column") and ("last row, last column") wells on the same piece of labware. In the example labware shown in the deck schematic above, this would be the 'A12' and 'H12' wells.
5. Repeat steps 3-4 for each of the labware items that need calibration.
5. When setting up the experiment in your python code, apply the recorded manual offset values to each piece of labware. Example code:

```
tiprack = jubilee.load_labware('opentrons_96_tiprack_300uL.json', 0) #Load an opentrons 300uL tiprack into deck slot 0
tiprack.manual_offset([[<A1 X coord., A1 Y coord>], [<A12 X coord, A12 Y coord>], [<H12 X coord, H12 Y coord>]], save=True)
```

The `save` keyword argument is optional. If True, the offsets will save to the labware definition json file, allowing you to load them directly from the file next time you use the labware.

## Using a Lab Automation Deck + Labware

We can use our deck + labware definitions in code. First, we need to import relevant modules:

```python
from science_jubilee.Machine import Machine
from science_jubilee.Decks import Deck
```

We can then load a deck onto the machine, and labware into the deck:

```python
m = Machine()
deck = m.load_deck("<my_deck_definition>")
labware = deck.load_labware("<my_labware_definition>")
```

Note that we can omit the `.json` file extension. Let's take an example using a 24-well plate. Each labware is made up of a number of `Well` objects. We can access information like size and location of each well by its row-column identification (A1, A2, ...) or its index (0, 1, ...), where index 0 corresponds to A1:

```python
labware = deck.load_labware("greiner_24_wellplate_3300ul", 1)
well = labware["A1"]  # Identical to labware[0]
```

The value of `well` for this labware is:

```python
Well(name='A1', depth=16.5, totalLiquidVolume=3300, shape='circular',
     diameter=16.28, xDimension=None, yDimension=None, x=175.13,
     y=79.3, z=2.5, offset=[160.0, 7.3])
```

The value of `offset` comes from your specific automation deck calibration, and is used to adjust the position of each well. All other information derives from your labware definition. We can access each attribute directly:

```python
well.x      # 175.13, the x position of the well center
well.y      # 79.3,   the y position of the well center
well.depth  # 16.5,   the usable depth of

 this well from the top of the labware
well.z      # 7.5,    the thickness of the labware plate
```

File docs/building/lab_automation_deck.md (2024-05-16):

---
title: Lab Automation Deck
---

(lab-automation-deck)=
# Lab Automation Deck

```{figure} _static/deck.png
:scale: 50 %

Lab automation deck for Science Jubilee.
```

There is also a lab automation deck documented [on the Jubilee Wiki](https://jubilee3d.com/index.php?title=Lab_Automation_Plate). The deck attachment here is easier to build, requires less materials, and has slots off the build plate for disposal (e.g., sharps) containers. It also uses a flexure based design to accommodate slight labware heterogeneity.
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

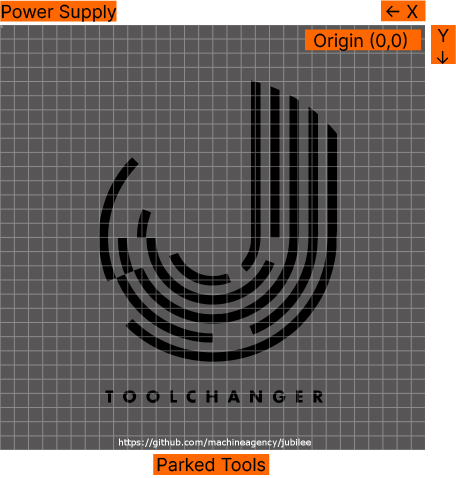
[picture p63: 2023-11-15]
docs/getting_started/_static/jubilee-coordinates.jpg

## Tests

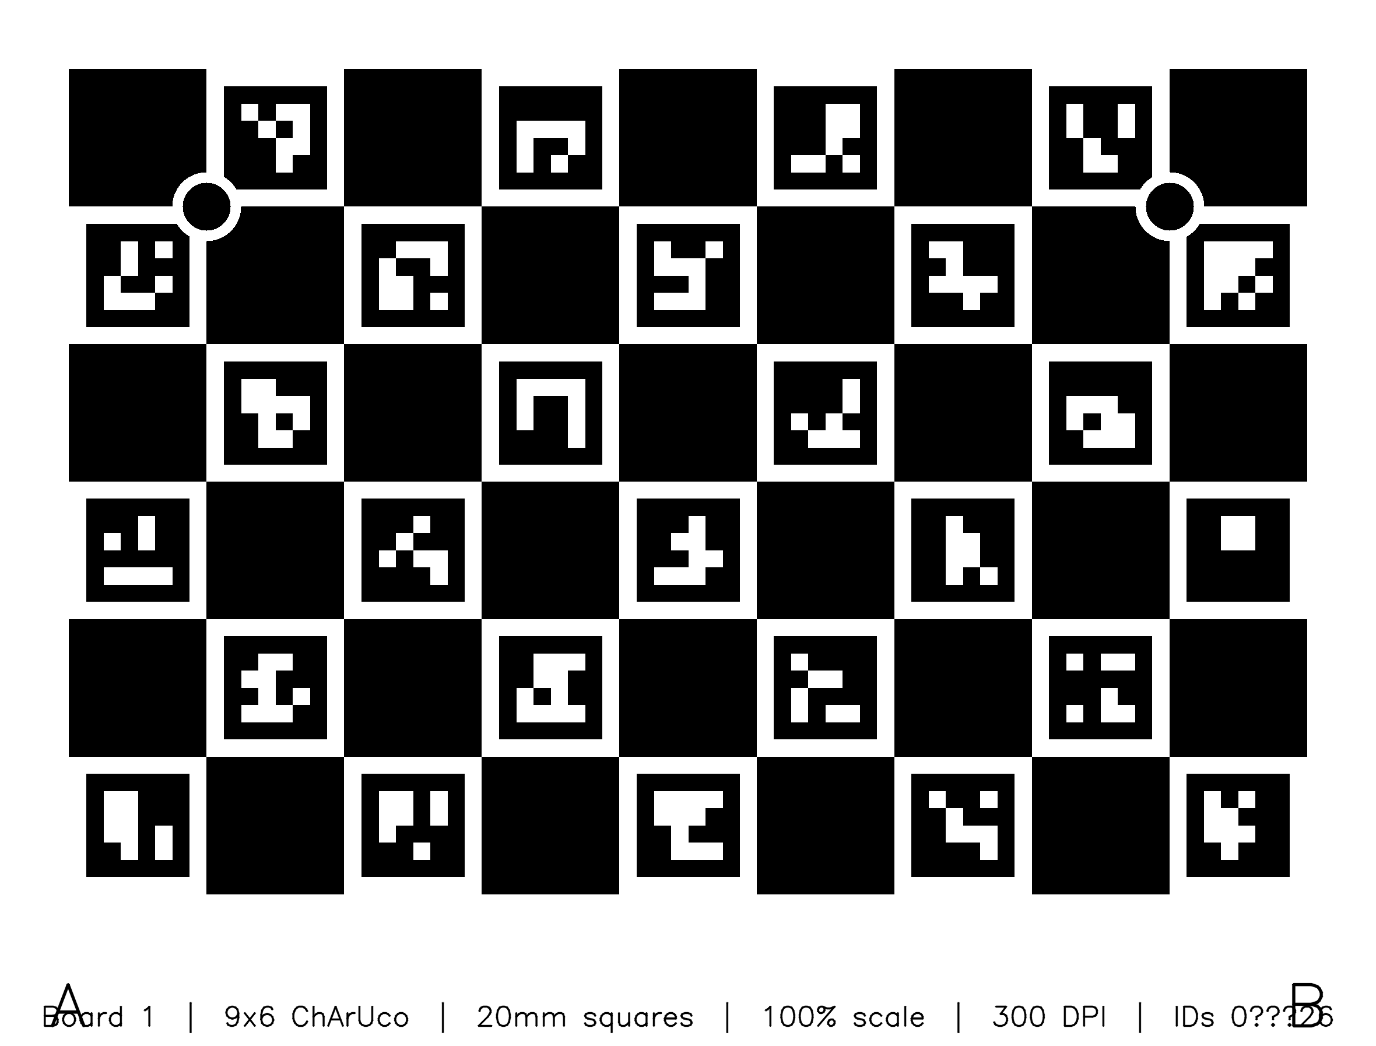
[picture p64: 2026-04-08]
src/science_jubilee/calibration/Birdseye/charuco_board_1.png

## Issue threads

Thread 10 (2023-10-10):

Check axis limits when picking up tool

brendenpelkie, 2023-10-10:
Axis limits should be checked and we should verify that they will not be exceeded when picking up a tool (machine.py, pickup_tool). Especially an issue for pipette.

bsubbaraman, 2023-10-11:
The `M208` command in the [default config.g](https://github.com/machineagency/jubilee/blob/c877bd2e889560c83da2a68479641a4f7f0d9b83/software/duet_config_files/duet3_mini_with_3hc/sys/config.g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) file should set the max travel limits, which will be adjusted for a tools x/y/z offsets. Which axes have you noticed are exceeded when picking up a tool?

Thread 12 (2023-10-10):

Pipette dispense safety check break

brendenpelkie, 2023-10-10:
Pipette tool axis safety checks raise errors when called from the transfer function. Comment says this did not occur when calling dispense directly.

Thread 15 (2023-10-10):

Refine next available pipette tip iteration

brendenpelkie, 2023-10-10:
Next available pipette tip should always be a clean unused tip. Currently if you use a tip then replace it, the used tip will be picked up as the next available tip. User should have to explicitly specify a tip location to get a dirty tip .

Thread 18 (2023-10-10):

Discuss deck layout and ordering

brendenpelkie, 2023-10-10:
Current deck layout and ordering (ie where slot #1 is) is backwards from how opentrons does it. Discuss if this is actually how we want it or if we want to stick with convention.

bsubbaraman, 2023-10-11:
Slot 1 is currently set to be closest to Jubilee's origin position. I think having it aligned with Jubilee's axes makes manual adjustments intuitive and some implementation details straightforward (e.g. we can just use the Opentrons labware definitions off-the-shelf), so my instinct is to keep the current layout to encourage people to 'buy in' to the Jubilee coordinate system. This could be beneficial to build a sound mental model of the machine should users want to make their own non-deck related applications in the future. But happy to change it if others feel that it is unnecessarily confusing for scientists already comfortable with OpenTrons!

bsubbaraman, 2023-11-08:
Closing this-- feel free to reopen if we should discuss more!

Closed 2023-11-08.

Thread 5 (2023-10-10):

Machine safe state after interrupt

brendenpelkie, 2023-10-10:
Interrupting a process can leave the machine in an unsafe state. Example: I keyboard interrupted during a pipette pickup. The machine had physically picked up the pipette but updated offsets were not applied yet. The next move crashed the machine.

Proposed fix: implement a 'max safe z' value that is the maximum possible z value required for safety in any available configuration with current labware (ie max safe z with pipette tip attached). If keyboard interrupt during process, move to this z and require user input to move forward.

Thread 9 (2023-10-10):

Implement logging

brendenpelkie, 2023-10-10:
Replace print statements with logging. Also add logging to log normal operations to a log file for experiment tracking and physical debugging.

- current debug statements should move to debug level logging
- Scientifically relevant actions (ie aspirate/dispense) should log pertinent details at a default level

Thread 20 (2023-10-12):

Incorrect processing of deck config file

bsubbaraman, 2023-10-12:
When calling `load_deck()` `Machine.py` [currently reads in the json file](https://github.com/machineagency/science_jubilee/blob/ba2617ef22116ae474059c5975bd25c4ad26d831/science_jubilee/Machine.py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), and then `Deck.py` tries to [read it again.](https://github.com/machineagency/science_jubilee/blob/ba2617ef22116ae474059c5975bd25c4ad26d831/science_jubilee/decks/Deck.py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).

Instead, I think the Deck initialization should just read the config directly, e.g.

```
class Deck(SlotSet):
  def __init__(self, config):
    self.deck_config = config
    self.slots_data = self.deck_config.get("slots", {})
    self.slots = self._get_slots()
    self._safe_z = 5
```

bsubbaraman, 2023-11-08:
Fix in PR #22

Closed 2023-11-08.

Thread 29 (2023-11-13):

Tool design upgrades

MariaPoliti, 2023-11-13:
I have made some modification to some of the tool holder designs (e.g., I've slightly modified the OT2 Pipette holder). I am wondering how we should deal with comminity modifications/upgrades to some of the 3D designs.

My proposal is to create a subfolder in each `tool_library/tool_folder/` called 'update/` or `modification/` to have a log of changes made by users. In each, we shuold have the new STL design file and a description of how it differ from the base tool part/component. We can then also have a `depricated_versions/` in case a modification is "voted" to be the new base model.

I am open to suggestions or alternative ideas on how to handle that.

bsubbaraman, 2023-11-13:
I think that your proposed plan (i.e. a `modification/` folder alongside a short README) makes sense to me! Perhaps we can pair each modification with a github issue which starts a discussion on if the new design should be the new default, or simply be available as an alternative?

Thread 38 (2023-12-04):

picamera required dependeny

brendenpelkie, 2023-12-04:
The picamera package is listed as a dependency in setup.py, making science_jubilee uninstallable on a non-pi system (or at least my WSL ubuntu instance).

Proposed fix:
1. remove picamera from base install dependencies
2. add  steps to check install/manage install of picamera to camera tools that directly run on a pi

bsubbaraman, 2023-12-04:
Good catch-- currently it installs fine on mac or windows, but [the conditional check in setup.py](https://github.com/machineagency/science_jubilee/blob/39ba333df7cbecc58c52599d3cd4dbf56f385dc7/setup.py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) is currently if running on linux; I would propose changing this to check the os_name to only install on Raspberry Pi!

brendenpelkie, 2023-12-04:
That makes sense too. That's cool I didn't know you could do conditional installs like that!

brendenpelkie, 2023-12-08:
Addressed by #41. Checks for pi camera by checking for aarch64 machine instead of linux platform.

bsubbaraman, 2024-02-27:
Reopening because I just tried a fresh install on my pi 3 which isn't aarch64 so picamera doesn't install! I'll submit a pull request with a fix for this one

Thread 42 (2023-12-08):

Well plate alignment tool

brendenpelkie, 2023-12-08:
### Feature request details

Add a software tool workflow to set wellplate offsets and alignment. This would look something like it does  on opentrons. Here, the user is guided through a series of steps to place the tool tip in a reference location over the well plate, then use this to update well plate locations. Ideally this would apply a location correction as well.

Sonication station supports this and I implemented this on my color mixing demo so the logic is written, this is a matter of integrating this into the new library.

bsubbaraman, 2023-12-11:
Just to clarify, is this meant as a way to create a interactively create a new labware definition instead of using [the labware designer ](https://labware.opentrons.com/create/), or something else? If there's a link to the relevant OpenTrons documentation that might be helpful!

brendenpelkie, 2023-12-11:
This is to fine-tune wellplate alignment after you have it loaded, before you run an experiment. Even on the OT2 deck there is always some variation in positioning, so it is useful to have a method to account for that. Its mentioned in the OT2 docs here but haven't found anything more detailed: [https://docs.opentrons.com/v2/robot_position.html#using-labware-position-check](url).

OT2 doesn't do a rotation correction, while the original sonication station position check does do a rotation correction by having the user sample 3 points then doing some trigonometry. I think this is worth having given the loose tolerances of our current deck designs.

bsubbaraman, 2023-12-11:
Gotcha! That seems great, especially for using 96-well plates and beyond

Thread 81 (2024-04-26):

Consider adding an edit in GitHub link to each page

sgbaird, 2024-04-26:
### Feature request details

https://pydata-sphinx-theme.readthedocs.io/en/stable/user_guide/source-buttons.html#add-an-edit-button

https://github.com/pydata/pydata-sphinx-theme/issues/62

Closed 2024-04-30.

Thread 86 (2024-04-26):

OK with a switch to Markdown with myst-parser instead of RST?

sgbaird, 2024-04-26:
### Feature request details

Any strong attachment to RST?

bsubbaraman, 2024-06-19:
The switch to markdown was done by Sterling and very welcome :)

Closed 2024-06-19.

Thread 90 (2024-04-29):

Dead link for pipette tool wiring

sgbaird, 2024-04-29:
### Duet3D Firmware Version

_No response_

### Steps to reproduce this bug

https://machineagency.github.io/science_jubilee/building/pipette_tool.html#pipette-tool links to https://github.com/machineagency/science_jubilee/blob/main/tool_library/OT2_pipette/assembly_docs/OT_Wiring_Diagram_V1.pdf

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

Also, maybe worth linking to the build instructions tutorial from the POSE workshop?

bsubbaraman, 2024-06-19:
The link was updated in the new docs!

Closed 2024-06-19.

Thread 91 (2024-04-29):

Which build plate should I use for the lab automation deck?

sgbaird, 2024-04-29:
### Topic

The heater version doesn't seem to be the right size.

https://machineagency.github.io/science_jubilee/building/lab_automation_deck.html#lab-automation-deck

Is this the one I should get? https://www.filastruder.com/products/jubilee-magbed-by-mandala-rose-works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

bsubbaraman, 2024-06-19:
Thanks for sharing the process Sterling! Closing, feel free to re-open if there are still open questions about this

Closed 2024-06-19.

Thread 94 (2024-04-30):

Consolidate camera options

brendenpelkie, 2024-04-30:
### Feature enhancement details

We currently have 3 camera tools: 'Camera', which runs on raspberry pis directly, 'WebCamera' which connects to an http endpoint serving jpegs, and the better-named in-progress 'HTTPCamera' from Ethan which does something similar. This is confusing and hard to support. I propose we consolidate this into one 'camera' tool that supports each method for image acquisition. This can be specified in a config file/ at object instantiation.

jschrier, 2025-07-01:
Additionally, the [POSE25 demonstration code](https://github.com/machineagency/POSE25/blob/main/camera/TakingPictures.ipynb) appears to use yet another (unreleased?) `WebCam`  which implements different methods and features...

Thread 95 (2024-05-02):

Pipette tip state updates after pickup

brendenpelkie, 2024-05-02:
### Duet3D Firmware Version

_No response_

### Steps to reproduce this bug

The tip state (ie pipette has tip true or false) seems to update after the pipette pickup step happens physically. This makes it possible to have a python state of tip=False while the meatspace state is tip=True if you interrupt at just the right moment. we should switch this so the python state updates before moving to pickup the tip.

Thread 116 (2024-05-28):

Installation on Raspberry Pi 5 and bookworm with OpenCV dependency

sgbaird, 2024-05-28:
Reported by @yakavetsiv when installing on Raspberry Pi 5 with Bookworm DuetPI OS
```
      -- Installing: /tmp/pip-install-vzi0mxu1/opencv-contrib-python_174a793d581f4484b688df56df0872c8/_skbuild/linux-aarch64-3.11/cmake-install/share/opencv4/lbpcascades/lbpcascade_silverware.xml
      Copying files from CMake output
      Traceback (most recent call last):
        File "/home/ac-duet/science-jubilee/.venv/lib/python3.11/site-packages/pip/_vendor/pyproject_hooks/_in_process/_in_process.py", line 353, in <module>
          main()
        File "/home/ac-duet/science-jubilee/.venv/lib/python3.11/site-packages/pip/_vendor/pyproject_hooks/_in_process/_in_process.py", line 335, in main
          json_out['return_val'] = hook(**hook_input['kwargs'])
                                   ^^^^^^^^^^^^^^^^^^^^^^^^^^^^
        File "/home/ac-duet/science-jubilee/.venv/lib/python3.11/site-packages/pip/_vendor/pyproject_hooks/_in_process/_in_process.py", line 251, in build_wheel
          return _build_backend().build_wheel(wheel_directory, config_settings,
                 ^^^^^^^^^^^^^^^^^^^^^^^^^^^^^^^^^^^^^^^^^^^^^^^^^^^^^^^^^^^^^^
        File "/tmp/pip-build-env-rxe8vw61/overlay/lib/python3.11/site-packages/setuptools/build_meta.py", line 230, in build_wheel
          return self._build_with_temp_dir(['bdist_wheel'], '.whl',
                 ^^^^^^^^^^^^^^^^^^^^^^^^^^^^^^^^^^^^^^^^^^^^^^^^^^
        File "/tmp/pip-build-env-rxe8vw61/overlay/lib/python3.11/site-packages/setuptools/build_meta.py", line 215, in _build_with_temp_dir
          self.run_setup()
        File "/tmp/pip-build-env-rxe8vw61/overlay/lib/python3.11/site-packages/setuptools/build_meta.py", line 268, in run_setup
          self).run_setup(setup_script=setup_script)
                ^^^^^^^^^^^^^^^^^^^^^^^^^^^^^^^^^^^^
        File "/tmp/pip-build-env-rxe8vw61/overlay/lib/python3.11/site-packages/setuptools/build_meta.py", line 158, in run_setup
          exec(compile(code, __file__, 'exec'), locals())
        File "setup.py", line 537, in <module>
          main()
        File "setup.py", line 267, in main
          setup(
        File "/tmp/pip-build-env-rxe8vw61/overlay/lib/python3.11/site-packages/skbuild/setuptools_wrap.py", line 706, in setup
          _classify_installed_files(
        File "setup.py", line 411, in _classify_installed_files_override
          with open(config_py, 'w') as opencv_init_config:
               ^^^^^^^^^^^^^^^^^^^^
      FileNotFoundError: [Errno 2] No such file or directory: '_skbuild/linux-aarch64-3.11/cmake-install/python/cv2/config-3.py'
      [end of output]

  note: This error originates from a subprocess, and is likely not a problem with pip.
  ERROR: Failed building wheel for opencv-contrib-python
  Building wheel for pyzmq (pyproject.toml) ... done
  Created wheel for pyzmq: filename=pyzmq-26.0.3-cp311-cp311-linux_armv8l.whl size=707528 sha256=d17b9efc6687e83c0339d6eba3083ef72a25bd3490b1a88445c77b254016a982
  Stored in directory: /home/ac-duet/.cache/pip/wheels/f4/44/89/690cd7f3816cdecb2a681775e2fc6f23c25bd0005125ea29ba
Successfully built science-jubilee pyzmq
Failed to build opencv-contrib-python
ERROR: Could not build wheels for opencv-contrib-python, which is required to install pyproject.toml-based projects
```

sgbaird, 2024-05-30:
In my haste, posted separately at https://github.com/machineagency/science-jubilee/issues/121, but moving to here to consolidate.

Reported by @yakavetsiv when trying to separate out `science-jubilee` from Open CV dependency, using Raspberry Pi 5 with bookworm Duet firmware, as a follow-up to https://github.com/machineagency/science-jubilee/issues/116.

Splitting dependencies is currently underway #120. @yakevitsiv I suggest switching to the `deps` branch and using that to debug. Planning to merge once I've verified installation is OK.

```python
---------------------------------------------------------------------------
ImportError                               Traceback (most recent call last)
File ~/science-jubilee/.venv/lib/python3.11/site-packages/numpy/core/__init__.py:24
     23 try:
---> 24     from . import multiarray
     25 except ImportError as exc:

File ~/science-jubilee/.venv/lib/python3.11/site-packages/numpy/core/multiarray.py:10
      9 import functools
---> 10 from . import overrides
     11 from . import _multiarray_umath

File ~/science-jubilee/.venv/lib/python3.11/site-packages/numpy/core/overrides.py:8
      7 from .._utils._inspect import getargspec
----> 8 from numpy.core._multiarray_umath import (
      9     add_docstring,  _get_implementing_args, _ArrayFunctionDispatcher)
     12 ARRAY_FUNCTIONS = set()

ImportError: libopenblas.so.0: cannot open shared object file: No such file or directory

During handling of the above exception, another exception occurred:

ImportError                               Traceback (most recent call last)
File ~/science-jubilee/.venv/lib/python3.11/site-packages/numpy/__init__.py:130
    129 try:
--> 130     from numpy.__config__ import show as show_config
    131 except ImportError as e:

File ~/science-jubilee/.venv/lib/python3.11/site-packages/numpy/__config__.py:4
      3 from enum import Enum
----> 4 from numpy.core._multiarray_umath import (
      5     __cpu_features__,
      6     __cpu_baseline__,
      7     __cpu_dispatch__,
      8 )
     10 __all__ = ["show"]

File ~/science-jubilee/.venv/lib/python3.11/site-packages/numpy/core/__init__.py:50
     27     msg = """
     28
     29 IMPORTANT: PLEASE READ THIS FOR ADVICE ON HOW TO SOLVE THIS ISSUE!
   (...)
     48 """ % (sys.version_info[0], sys.version_info[1], sys.executable,
     49         __version__, exc)
---> 50     raise ImportError(msg)
     51 finally:

ImportError:

IMPORTANT: PLEASE READ THIS FOR ADVICE ON HOW TO SOLVE THIS ISSUE!

Importing the numpy C-extensions failed. This error can happen for
many reasons, often due to issues with your setup or how NumPy was
installed.

We have compiled some common reasons and troubleshooting tips at:

    https://numpy.org/devdocs/user/troubleshooting-importerror.html

Please note and check the following:

  * The Python version is: Python3.11 from "/home/ac-duet/science-jubilee/.venv/bin/python3"
  * The NumPy version is: "1.26.4"

and make sure that they are the versions you expect.
Please carefully study the documentation linked above for further help.

Original error was: libopenblas.so.0: cannot open shared object file: No such file or directory

The above exception was the direct cause of the following exception:

ImportError                               Traceback (most recent call last)
Cell In[1], line 1
----> 1 from science_jubilee.Machine import Machine
      3 m = Machine()                 # a new machine, called 'm'
      4 m.move_to(x=100, y=50, z=200) # moves to the absolute position (100, 50, 200)

File ~/science-jubilee/src/science_jubilee/Machine.py:16
     13 import requests  # for issuing commands
     14 from requests.adapters import HTTPAdapter, Retry
---> 16 from science_jubilee.decks.Deck import Deck
     17 from science_jubilee.tools.Tool import Tool
     19 # TODO: Figure out how to print error messages from the Duet.
     20
     21
     22 # copied from machine agency version, may not be needed here

File ~/science-jubilee/src/science_jubilee/decks/Deck.py:6
      3 from dataclasses import dataclass
      4 from typing import Dict, Tuple
----> 6 from science_jubilee.labware.Labware import Labware
      9 @dataclass
     10 class Slot:
     11     """Class that defines a slot on the Jubilee deck.
     12     Each slot has a unique index, offset, and can have a labware associated with it.
     13
   (...)
     21     :type labware: :class:`Labware`
     22     """

File ~/science-jubilee/src/science_jubilee/labware/Labware.py:9
      6 from math import acos, cos, sin, sqrt
      7 from typing import Dict, Iterable, List, NamedTuple, Tuple, Union
----> 9 import numpy as np
     12 @dataclass
     13 class Well:
     14     """A class representing a well of a labware.
     15
     16     Each Well is associated with a specific name, depth, total liquid volume, shape, diameter,
   (...)
     20     :rtype: :class:`Well`
     21     """

File ~/science-jubilee/.venv/lib/python3.11/site-packages/numpy/__init__.py:135
    131 except ImportError as e:
    132     msg = """Error importing numpy: you should not try to import numpy from
    133     its source directory; please exit the numpy source tree, and relaunch
    134     your python interpreter from there."""
--> 135     raise ImportError(msg) from e
    137 __all__ = [
    138     'exceptions', 'ModuleDeprecationWarning', 'VisibleDeprecationWarning',
    139     'ComplexWarning', 'TooHardError', 'AxisError']
    141 # mapping of {name: (value, deprecation_msg)}

ImportError: Error importing numpy: you should not try to import numpy from
        its source directory; please exit the numpy source tree, and relaunch
        your python interpreter from there.
[ ]:
```

Comments from @bsubbaraman:
- Bookworm was released recently, so OpenCV for that version hasn't been debugged/integrated yet

Related #94

yakavetsiv, 2024-05-30:
The following solution for Issue #121 was found : `sudo apt-get install libopenblas-dev`

Closed 2024-06-14.

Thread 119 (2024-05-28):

Install error on Ubuntu

brendenpelkie, 2024-05-28:
### Duet3D Firmware Version

_No response_

### Steps to reproduce this bug

### Steps:
1. Set up fresh Ubuntu on WSL install with fresh conda environment (python 3.9)
2. Pip install science-jubilee
....

Install errors out due to spidev wheel build failure. Commenting out ` adafruit-mcp4725` requirement in setup.cfg avoids this error.

Possible fix: Remove  adafruit-mcp4725 requirement from general science-jubilee library or make install platform dependent (?)

brendenpelkie, 2024-06-12:
This was due to missing gcc.

Closed 2024-06-12.

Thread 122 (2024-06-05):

Pipette return tip raises ValueError when no tip attached

brendenpelkie, 2024-06-05:
### Duet3D Firmware Version

_No response_

### Steps to reproduce this bug

### Steps:
1. Return tip from 'transfer' function tip logic or other means
2. Try to return a tip directly with P300.return_tip()

Expected behavior: at worst a warning that tip not attached
Actual behavior: error out

....

### Snippet:

```python

// Paste your code here :)

```

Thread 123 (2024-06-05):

Pipette documentation lists mix arguements incorrectly

brendenpelkie, 2024-06-05:
### Duet3D Firmware Version

_No response_

### Steps to reproduce this bug

The documentation for the transfer function for the pipette lists the order of the values for the 'mix' keyword argument backwards. Current docs list is (number of times to mix, volume to mix) but code takes (volume to mix, number of times to mix)

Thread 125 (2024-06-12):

Documentation re-org: Decide where in-depth tool documentation lives

brendenpelkie, 2024-06-12:
### Feature request details

Right now the only tool documentation is the build guides under 'build guides'. We need to add to this so that there are usage guides on how to do things with the software and tool as well. This is especially true for the pipette tool, where new users currently have to intuit how the whole thing works from the api docstrings. I think it makes sense to lump all of the documentation for each tool in one place, so the build guide, software setup guide, usage guide, and examples all live together. To support this I propose renaming the 'build guides' section of the documentation to 'tool guides' or similar. Also open to other thoughts on how to organize more complete tool documentation.

sgbaird, 2024-06-27:
Sorry it took a while to get back to this!

First including prior comments from #130:

Blair:
> How do we want to organize the docs? 'Getting Started' currently primarily refers to the science-jubilee python codebase. Should we rename 'Getting Started' to 'Using science-jubilee to control your machine' or something? Then maybe we can divide the New User Guide information between the 'building a jubilee' and the software sections? I also see the utility in having a high-level end-to-end guide which gives people a sense in what needs to happen to go from nothing to an experiment.

sgbaird, 2024-06-27:
Brenden:

> Great to see this, I didn't realize this was in progress when I added the new user guide! I think we are bumping up against some tension between having these docs be for "science-jubilee, the python package for controlling Jubilee" and "science Jubilee, the place to come learn how to do experiments with Jubilee". I would advocate for leaning into the latter in our docs and making science-jubilee docs as much of a one-stop-shop for jubilee guidance as possible. Jubilee for science is really starting to get some traction in the community, and we should make sure new users have a clear path forward when getting started. There might be other organizational schemes for this that are worth considering, but we should settle on something. (ex, split the python package docs and general guidance docs). I opened https://github.com/machineagency/science-jubilee/issues/125 with the goal of discussing this. I think we should consider how to organize the entire project as well, in addition to the docs. Are we outgrowing the current setup of having everything (code, tools, config, guidance/docs) in one github repo, or is this a simple solution that gets the job done?

> Back to the original question, I think it makes sense to have an obvious landing section aimed at someone who heard about Jubilee somewhere and wants to see what it's about. This might look like the front page but with more details, maybe a text version of how we introduce Jubilee in talks/posters/etc. Then the obvious next step might be something like my 'new user guide' that gives a detailed walkthrough of how to get up and running on Jubilee, from buying the kit all the way to running an experiment. 'Getting started' might be a bit of an understatement for this section.

> I'm currently onboarding 3 new Jubilee users (2 MechE students and 1 ChemE PhD student). I expect to have clearer thoughts on this in a week or so after seeing how they feel about the learning process.

sgbaird, 2024-06-27:
> Great to see this, I didn't realize this was in progress when I added the new user guide!

Thanks! That was my bad for not seeing the new user guide sooner 😅

> I think we are bumping up against some tension between having these docs be for "science-jubilee, the python package for controlling Jubilee" and "science Jubilee, the place to come learn how to do experiments with Jubilee". I would advocate for leaning into the latter in our docs and making science-jubilee docs as much of a one-stop-shop for jubilee guidance as possible. Jubilee for science is really starting to get some traction in the community, and we should make sure new users have a clear path forward when getting started.

Agreed!

> There might be other organizational schemes for this that are worth considering, but we should settle on something. (ex, split the python package docs and general guidance docs). I opened #125 with the goal of discussing this. I think we should consider how to organize the entire project as well, in addition to the docs.

I think it's worth some careful thought and discussing. In one sense, when someone says "I'm committed to getting a Science Jubilee", there are up-front need to knows and things that are OK if it comes later. Hardware to purchase and build/electronics/firmware/testing instructions are the up-front need to knows I think.

> Are we outgrowing the current setup of having everything (code, tools, config, guidance/docs) in one github repo, or is this a simple solution that gets the job done?

It's not out of question; however, in the near-term I would caution against splitting into two GitHub repos and instead focus on finding the right organization within the GitHub repo in terms of directory structure and on the website. Hardware, electronics, software, firmware, testing, documentation, and usage instructions all have some connection with each other, so splitting it up across repositories could have some unexpected downsides, especially since it wasn't designed from the start this way.

Some examples that come to mind are [Pioreactor](https://github.com/Pioreactor/pioreactor) and [Rodeostat](https://github.com/iorodeo/potentiostat). Interestingly, Pioreactor puts their CAD files on https://www.printables.com/@Pioreactor, and has a separate repo for the [docs](https://github.com/Pioreactor/docs.pioreactor), though the website makes it feel like most things are hosted under the same blanket.

FarmBot [hosts all the CAD models on OnShape](https://express.farm.bot/v1.1/extras/cad), PCB Layout/schematic on a Google Drive (linked to on CAD page), and a [top-level GitHub organization](https://github.com/FarmBot) that hosts repositories for a web app, Python driver, Arduino firmware, etc. (i.e., anything on that organization is specific to FarmBot). They actually have an entirely separate GitHub organization dedicated to documentation with quite a few repos: https://github.com/FarmBot-Docs.

OpenFlexure has a [Gitlab organization](https://gitlab.com/openflexure/) with separation of repos:

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

Some random observations:
- In general (not just these examples), I've noticed is that often a Web UI will be in a separate repo, perhaps because it's easy to use full-repo templates
- Pioreactor, OpenFlexure, and FarmBot all have dedicated discourse forums

> Back to the original question, I think it makes sense to have an obvious landing section aimed at someone who heard about Jubilee somewhere and wants to see what it's about. This might look like the front page but with more details, maybe a text version of how we introduce Jubilee in talks/posters/etc. Then the obvious next step might be something like my 'new user guide' that gives a detailed walkthrough of how to get up and running on Jubilee, from buying the kit all the way to running an experiment.

> 'Getting started' might be a bit of an understatement for this section.

"So, you want to build a Science Jubilee" 😄

> I'm currently onboarding 3 new Jubilee users (2 MechE students and 1 ChemE PhD student). I expect to have clearer thoughts on this in a week or so after seeing how they feel about the learning process.

Similarly, as soon as we get the 3D printed parts from Lukes Laboratory, we'll be raring to go with four Science Jubilee builds with the AC summer students.

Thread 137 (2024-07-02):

Duel 3 Electronic Backboard Assembly

ethraj2001, 2024-07-02:
### Feature request details

Hi there,

I was just wondering where I can find the instructions for the duet 3 electronics panel. I cannot seem to find it on the wiki. I only see the duet 2 electronics panel. The back panels are a little confusing so any help would be appreciated.

[duet2_electronics_panel_assembly.pdf](https://github.com/user-attachments/files/16073266/duet2_electronics_panel_assembly.pdf)

Regards
Ethan R.

sgbaird, 2024-07-02:
The documentation on that needs to be improved. For at least the wiring, there is https://github.com/machineagency/science-jubilee/blob/main/docs/pdfs/jubilee_wiring_colormix.pdf and https://raw.githubusercontent.com/machineagency/jubilee/main/frame/assembly_instructions/wiring/duet3_mini/duet3_mini_frame_wiring.png.

There is [a picture of `reefingninja`'s setup from the Jubilee discord](https://discord.com/channels/627982902738681876/627988602269335568/1182078408084172871) (not Science Jubilee discord):

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

ethraj2001, 2024-07-02:
okay I see a wiring and layout but I am not sure what screws to use etc.

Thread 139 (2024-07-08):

Consider removing/changing the build plate instructions

sgbaird, 2024-07-08:
A lot of the content is specific to the heating pad, so this can either be marked as optional or removed entirely.
https://science-jubilee.readthedocs.io/en/latest/building/build_plate.html

I think the default from Filastruder is the build plate with embedded magnets.

This also relates to https://science-jubilee.readthedocs.io/en/latest/building/building_a_jubilee.html#hardware. Should the PEI plate + magnetic sticky sheet be nixed from the recommendation (or at least marked as optional or with an asterisk clarification that it's only needed for 3D printing).

Similarly, there will be places where there are deviations between the build instructions and the Filastruder kit, e.g., because certain steps are already carried out. For example, I'm thinking about wiring harnesses and cable assemblies. Similar to above, these can be marked as optional or removed or clarified with a note.

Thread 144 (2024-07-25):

Possible incorrect parking post files for pipette tool

sgbaird, 2024-07-25:
I think the [parking post files](https://github.com/machineagency/science-jubilee/tree/main/tool_library/OT2_pipette/designs/Tool_post) for the pipette tool may be the incorrect size. I think @yakavetsiv even made a custom version of the [3D only](https://github.com/machineagency/science-jubilee/tree/main/tool_library/OT2_pipette/designs/3D_only) designs to accommodate our use of the incorrect parking post files 🙃

yakavetsiv, 2024-07-26:
The models for reinforced and extended parking post are attached to the [OT-2 pipette tool #146]

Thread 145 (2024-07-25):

Update the wiring instructions for the endstop & the BOM

ststewa3, 2024-07-25:
- The wiring instructions only show how to connect the pins on the OT-2 to the pins on the Duet 3 Mini and 3HC. It would be useful to also include a diagram of how to wire the endstop to the OT-2.

- The [BOM](https://docs.google.com/spreadsheets/d/1Bp4ZdpHsX01EHIsc5mqbzi92CpQlax4KNS-QtPmUZUM/edit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) should include any additional wiring or equipment needed to wire the OT-2 to the Jubilee.

- In the BOM, [this endstop](https://www.digikey.com/en/products/detail/e-switch/SS0750300F070P1A/3778167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) is listed, but on the Science Jubilee website, [this endstop](https://www.digikey.ca/en/products/detail/e-switch/SS0750301F020P1A/2639077) is listed for the 3D printed only design. Probably only one endstop should be suggested.

yakavetsiv, 2024-07-26:
Here is the list of parts I ordered from Canadian Amazon, Filastruder, and Digi-Key. It does not include some parts I had leftover from the Jubilee assembly, which I used to wire the connectors to the Duet3 boards.

OT-2 pipette
1. https://www.filastruder.com/collections/jubilee/products/jubilee-tool-baby-bullet-harness
2. https://www.digikey.ca/en/products/detail/e-switch/SS0750301F020P1A/2639077
3. https://www.amazon.ca/gp/product/B00O9Y6FL6/ref=ox_sc_act_title_26?smid=A30WUG2ZDGM0XM&psc=1
4. https://www.filastruder.com/products/e3d-toolchanger-blank-tool-plate?_pos=2&_sid=041c73f09&_ss=r
5. M3 x 12mm x2
6. M3 x 16mm x2
7. M2.5 x 10
8. https://www.amazon.ca/Antrader-Ribbon-Cable-2-54mm-Connectors/dp/B07P77YRB2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
9. https://www.amazon.ca/gp/product/B09VFBYPND/ref=ox_sc_act_title_24?smid=A323R3SPXTWZAH&psc=1
10. https://www.amazon.ca/gp/product/B09MQ9815Q/ref=ewc_pr_img_3?smid=A1R2502RY7O6HU&psc=1

Tools:
1. Allen keys for M3 and M2.5 screws
2. https://www.amazon.ca/gp/product/B007R2JEM4/ref=ox_sc_act_title_25?smid=A64W1E1ZZHST0&psc=1
3. Solder Iron

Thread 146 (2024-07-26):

OT-2 pipette tool

yakavetsiv, 2024-07-26:
### Feature enhancement details

The current models of the 3D printed OT-2 adapter have multiple issues:

1. Tool Post Width: The tool post is wider than the adapter, causing misalignment.
2. Base for Wedge Plate: The base is too deep, preventing it from locking properly.
3. Wings and Wedge Plate: The wings are too low, and as a result, the wedge plate hole is also too low, which prevents proper locking.
4. Plastic Springs: The plastic springs tend to compress excessively and require reinforcement.
5. Metal Plate Requirement: There is a need for a metal plate to improve structural integrity.
6. Shift of the pipette from a perpendicular alignment over time.
7. Absence of model for wire holder

Attached are the *.STL models of the updated OT-2 holder for your review.

[OT-2 printing.zip](https://github.com/user-attachments/files/16385597/OT-2.printing.zip)

brendenpelkie, 2024-08-21:
Thanks for these suggestions @yakavetsiv.

1. Have you put your re-designed parts into use? Have they resolved any of these issues?
2. Yes the tool post published with the pipette tool is the wrong size for the 3D printed version. That needs to be updated.
3. What do you mean by 'metal plate requirement'? The currently published 3D printed flexure mount uses a machined tool changer plate. (https://github.com/machineagency/science-jubilee/blob/main/tool_library/OT2_pipette/assembly_docs/OT2_Pipette_3D_only_assembly_instructions.pdf). Is this what you meant, or are you referring to something else?
4. How is the 'bracket-P200' part in your stl files assembled? Does that clip around the pipette body somehow? Is this part for vertical alignment?

If you've put your redesign into use and think it is an improvement over the original, it would be great to incorporate your version as the new 3D printed option.

yakavetsiv, 2024-08-22:
1. Yes, I'm currently using multiple OT-2 pipette tools with the designed parts, and the updated components have resolved all the previously mentioned issues.
2. I used the published tool post as a reference.
3. Apologies for the incorrect terminology—I was referring to a machined tool changer plate. The updated design no longer requires this part; only the metal balls and Delrin insert are needed for the locking mechanism.
4. I’ll send you photos of the assembly tomorrow. It is indeed clipping around the pipette body, leaving only the vertical movement unconstrained.

PS. I also filmed the wiring of the OT-2 tool. Will be happy to shape it for WIKI

brendenpelkie, 2024-08-22:
Glad to hear you got it working. It sounds like this design improves on our currently published version. If you are OK with it, I can replace the current 3D printed version design with your updated one. Would you be able and willing to share your CAD files in addition to the STLs?

A wiring video would be a great addition to our pipette tool documentation!

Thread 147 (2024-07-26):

Bed plate holders

yakavetsiv, 2024-07-26:
### Feature enhancement details

The holder models from the [assembly page](https://jubilee3d.com/index.php?title=Lab_Automation_Plate) are designed to be used without heat inserts, which could be a great option. I also recommend adding a note that the holder should be printed vertically to avoid delamination in the future.

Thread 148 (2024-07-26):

Jubilee Aluminum Front Corner Brackets

yakavetsiv, 2024-07-26:
### Feature enhancement details

I suggest adding the [Jubilee Aluminum Front Corner Brackets by Mandala Rose Works](https://www.filastruder.com/collections/jubilee/products/jubilee-aluminum-front-corner-brackets-by-mandala-rose-works) to the main Jubilee kit, along with the [Left Corner Spacer](https://github.com/machineagency/jubilee/blob/master/frame/upgrades/aluminum_corner_plates/fabrication_exports/3d_printed_parts/left_machined_corner_spacer.STL) and [Right Corner Spacer](https://github.com/machineagency/jubilee/blob/master/frame/upgrades/aluminum_corner_plates/fabrication_exports/3d_printed_parts/right_machined_corner_spacer.STL) in the main model repository. Additionally, please include 6x M5 buttonhead screws, 25mm long, with 6x M5 washers.

brendenpelkie, 2024-08-21:
Good suggestion. We also like to build new machines with the aluminum Z yokes and motor plates to improve rigidity and solvent compatibility. I've added these recommendations as an option in the purchase guide with #156

Closed 2024-08-21.

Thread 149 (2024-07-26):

Laser cutting of Delrin for Lab automation bed

yakavetsiv, 2024-07-26:
### Topic

Fabricating the lab automation deck from a 12x24in Delrin sheet using a laser cutter proved to be challenging. Despite optimizing the settings (see the final settings in the attached photo), the resulting parts still required manual cutting from the sheet using a razor and exhibited thermal warping.

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

Suggestions are highly appreciated

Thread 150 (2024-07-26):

Issue with safe-z state management

brendenpelkie, 2024-07-26:
### Duet3D Firmware Version

_No response_

### Steps to reproduce this bug

### Steps:
1. Load a new deck instance in python
2. Load labware associated with that deck/machine
3. Re-run the deck cell

Now your safe-z height is the default safe z for the deck, but the labware is still defined and can be associated with tools and accessed by the machine. Since the safe-z is too low, you will have a collision. We ran into this issue when picking up a pipette tip.
....

### Snippet:

```python

// Paste your code here :)

```

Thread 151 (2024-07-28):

Updating travel docs

sgbaird, 2024-07-28:
For example, Science Jubilee dimensions, 10" minimum height if using short extrusions

brendenpelkie, 2024-08-20:
@sgbaird could you add a bullet point to the "Packing and Transport" section of the jubilee travel docs mentioning how your packing strategy for Accelerate worked out? I think that will be a useful anecdote for future Jubilee travel.

sgbaird, 2024-08-20:
Summarizing here and then will port over a trimmed version:

300' of bubble wrap, cardboard slats, packing wrap, and two patio furniture bags

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

Having to unwrap everything at the airport due to the bag not fitting through the oversized scanner at YYZ. During re-packing, one of belts came loose. Can be fixed.

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

Then, it not coming on the same plane and it coming too late for the actual demo.

Return trip had almost no issues (fit through the scanner, picked it up).

brendenpelkie, 2024-08-21:
Awesome thanks! Did it survive OK? Any damage? Was the alignment reasonable after it made it home?

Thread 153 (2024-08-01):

Parking post height adjustment

sgbaird, 2024-08-01:
Mention the height adjustment required when mounting a new tool in the tools docs, i.e., tool positioning

brendenpelkie, 2024-08-20:
Yes this is important to add. Our documentation would benefit from a re-written tool parking post position tutorial that includes z-axis adjustment and other tweaks. I'll work on adding this.

sgbaird, 2024-08-20:
Forgot to add: https://youtube.com/shorts/_3stUKidY7Y?si=29VHJ1fLYcNBsfVH and https://youtube.com/shorts/EEWD-wCFl9g?si=dWMmSwy5AnTrTyrD can be added to help address this

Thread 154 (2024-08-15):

Heat Set pieces and Force

owen-melville, 2024-08-15:
Overall issue: When I tried to tighten the pieces in the "Motor Installation" section of the "Toolchanger Remote Elastic Lock Assembly" the heat-set brass inserts came out, and the piece was not held in.
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

Suggestions:
-The 3D printed part (RLB-11) seems to have too much space for the inserts, which doesn't allow the insert to be as stiffly locked in place as it could be
-In the instuctions, make a note about not over-tightening
-Using superglue on the inserts?

owen-melville, 2024-08-15:
I tried again with new piece... exact same issue... I am proceeding but it does not seem very secure and I can see the heart set insets coming out

owen-melville, 2024-08-15:
I think potentially this piece should have a different default orientation (large side down) for printing

owen-melville, 2024-08-15:
to be honest I have seen lots of the heat set inserts start to pull out as I'm assembling

bsubbaraman, 2024-08-15:
Hey @owen-melville thanks for the comments! Checking a couple things off the bat, since you said this is happening on multiple parts: did you adjust your slicer settings to use 6 perimeter layers? (This is important for parts with heat set inserts, along with the other default print settings listed here https://jubilee3d.com/index.php?title=3D_Printed_Parts).  And if you measure the interior diameter of your printed parts, is it ~5.1mm?

owen-melville, 2024-08-15:
Yes - using Bambu studio on advanced I set "Wall Loops" to 6 and infill to 20% but "Outer Perimeter" layer first was not a clear option. I didn't measure but the holes did seem a bit large, there was some resistance to push the piece in with the soldering iron but it didn't seem like much... I am wondering why this piece has the default orientation that it does.... When you put it "Large" size down, the holes are printed vertically rather than horizontally. The only holes that are switched to horizontal are the small holes that I needed to use a drill to do pilot holes on anyway.

owen-melville, 2024-08-15:
It is caused by the holes being printed horizontally...  See top of the two. Has this come up before?
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

bsubbaraman, 2024-08-16:
Thanks for the extra tests & pics! I haven't run into this personally, but print orientation can definitely effect dimensional accuracy. There might be some printer calibration routines to mitigate the effects--holes coming out as ovals is a problem that is documented here https://forum.bambulab.com/t/why-ovals-and-not-circles/7354 on Bambu printers and the thread might have possible fixes (assuming you're using a Bambu printer, since you mentioned Bambu studio earlier).

In general the print orientations are chosen to maximize mechanical strength/minimize supports. In this case though, I think an print orientation might be a good fix!

owen-melville, 2024-08-16:
Yeah - Our colleague printed on another Bambu printer (different one, different building) and apparently had the same result. I'll take a look at that thread and thanks for sharing!

yakavetsiv, 2024-08-17:
In addition to the printer settings, another potential issue could be the outer diameter of the heat inserts. The kit includes smaller heat inserts (shown on the right in the photo), which are too small for the intended holes. Using heat inserts with a larger outer diameter (shown on the left in the photo) resolves this problem.
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

brendenpelkie, 2024-08-20:
For future procurement needs, McMaster Carr has the correct sized 5.1mm OD inserts as product number 94180A331. (https://www.mcmaster.com/94180A331/). Filastruder also used to stock these but I'm not seeing them on their website currently.

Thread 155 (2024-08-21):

Add reccomended upgrade parts to build shopping list

brendenpelkie, 2024-08-21:
### Feature request details

Add recommended machined upgrades (z yokes, front corner bracket, motor mount plates) to Jubilee build guide page in docs (https://science-jubilee.readthedocs.io/en/latest/building/building_a_jubilee.html#jubilee-build-resources)

brendenpelkie, 2024-08-21:
Closed with #156

Closed 2024-08-21.

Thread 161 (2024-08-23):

Pipette dispense/aspirate rate in uL/time

brendenpelkie, 2024-08-23:
### Feature request details

Currently the OT2 pipette tool dispense rate is in mm/minute. It would be more useful to have control in units of uL/seconds or minutes. This would do the conversion within the pipette driver code, instead of making the user do it themselves.

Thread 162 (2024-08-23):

Manage tool intervention error when homing from python

brendenpelkie, 2024-08-23:
### Duet3D Firmware Version

_No response_

### Steps to reproduce this bug

### Steps:
1. Home tool from the python library with a tool attached. This will trigger a 'tool attached' error and require user intervention to correct. This can also happen if you are homing with the tool changer at a high rotation angle.

In the duet web control interface, a dialogue box pops up telling the user to remove the tool and click OK to continue homing. Python does not display the error or any clue to fix it and will just hang on the homing step.
....

### Snippet:

```python

// Paste your code here :)

```

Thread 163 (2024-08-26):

Investigate intermittent hang issues over HTTP

brendenpelkie, 2024-08-26:
### Feature enhancement details

When running the duet board in standalone mode (with commands sent over HTTP API), Jubilee will sometimes 'hang' intermittently between commands. Based on an initial investigation, it looks like we are not managing sessions correctly and have mis-configured our retry back-off. This could be part of the problem, or it could be something else.

API documentation: https://github.com/Duet3D/DuetSoftwareFramework/wiki/REST-API

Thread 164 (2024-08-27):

Instructions Could be More Clear

owen-melville, 2024-08-27:
### Feature enhancement details

Lock Actuator Tension Check step in the CoreXY Frame Assembly could be more clear.

There are two wire ends on lock actuator pulley. Which one is meant to be tight and which one loose at which stage is unclear. I've had trouble and witnessed other people having trouble with this step (~3 people total). I wonder if there could be an illustration involving the wires in each stage of tightening.

bsubbaraman, 2025-03-27:
Way late on this, but there's a video tutorial waiting to be edited that shows this (and all other build steps) in more detail. I'll follow up with a timeline on that getting posted.

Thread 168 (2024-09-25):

Labware manual offset correction error

brendenpelkie, 2024-09-25:
### Duet3D Firmware Version

_No response_

### Steps to reproduce this bug

The labware manual offset correction is not correctly offsetting well locations. This method allows users to correct the calculated labware well positions with three ground-truth corner well positions and apply a rotation correction. However, something in the rotation + translation math seems to be slightly off, resulting in calculated corner well positions that do not match the actual positions

### Steps:
1. Record 3 corner well positions as described in [docs](https://science-jubilee.readthedocs.io/en/latest/getting_started/deck_guide.html#labware-calibration)
2.  Run labware.manual_offset() function
3. inspect resulting well positions. Especially for the furthest wells from A1 (ex H12), they will likely be pretty far off.

brendenpelkie, 2024-09-30:
This was an issue on my end with incorrect labware reference points. The existing offset code should work fine.

brendenpelkie, 2024-10-17:
Actually there was a rotation correction bug, I'm not going crazy. Rotation only accounted for magnitude of theta, not direction. Fixed in #173

Closed 2024-09-30.

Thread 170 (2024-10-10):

Pipette documentation missing M208 command

zrwylie, 2024-10-10:
### Duet3D Firmware Version

_No response_

### Steps to reproduce this bug

### Steps:
1. Pipette motor requires M208 axis limit definition but missing from documentation

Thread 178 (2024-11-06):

Unable to call on the Machine class

jzhang-03, 2024-11-06:
Whilst I am able to import the `Machine` class, I am unable to call on it.
My code currently is:

```python
from science_jubilee.Machine import Machine
m = Machine()
```

The error this code is giving me is:

```
Warning: disconnecting this application from the network will halt connection to Jubilee.
Both `requests.post` and `requests.get` requests failed: HTTPConnectionPool(host='none', port=80): Max retries exceeded with url: /rr_model?key=seqs (Caused by NameResolutionError("<urllib3.connection.HTTPConnection object at 0x7fff642d5e50>: Failed to resolve 'none' ([Errno -2] Name or service not known)"))
Traceback (most recent call last):
  File "/home/robocop-99/science-jubilee/hello_world.py", line 3, in <module>
    m = Machine()
        ^^^^^^^^^
  File "/home/robocop-99/science-jubilee/src/science_jubilee/Machine.py", line 195, in __init__
    self.connect()
  File "/home/robocop-99/science-jubilee/src/science_jubilee/Machine.py", line 216, in connect
    response = json.loads(self.gcode('M409 K"move.axes[].homed"'))[
               ^^^^^^^^^^^^^^^^^^^^^^^^^^^^^^^^^^^^^^^^^^^^^^^^^^^
  File "/usr/lib/python3.11/json/__init__.py", line 339, in loads
    raise TypeError(f'the JSON object must be str, bytes or bytearray, '
TypeError: the JSON object must be str, bytes or bytearray, not NoneType
```

The machine is connected over wireless WiFi (not Ethernet). It is running on a raspberry pi. The python version that is being used is 3.11.2 and the OS used is Linux 6.6.47.

Prior to running my code, I didn't do anything but turn on the machine. The machine was not homed.

My current goal is trying to get the machine to simply move.
Some help and guidance on resolving this issue would be greatly appreciated.

Thank you

jzhang-03, 2024-11-08:
The solution was
``` python
m = Machine(address = "duet 3")
```

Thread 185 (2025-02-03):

Driver Failure

jzhang-03, 2025-02-03:
The U-Axis of the tool holder suddenly stopped moving for me. I received an error message that states: **"Driver 0.1 warning: phase A may be disconnected, phase B may be disconnected."** Driver 0.1 is the driver for moving the motor that controls the U-Axis of the tool holder. However, movement in the X, Y, and Z axis are all fine and result in no errors. The machine wasn't particularly hot either.

This error occurred after trying to home all the axes whilst accidentally having the gel extruder tool selected (but not actually loaded onto the tool holder). This resulted in the tool holder physically crashing into the frame of the jubilee. I didn't notice that I had the gel extruder tool selected, so I tried to home the machine a few times, which all resulted in the tool holder crashing into the machine. Once I had deselected the gel extruder, I was able to properly home the X, Y, and Z axis, however the U-Axis on the tool holder was no longer moving and the error message mentioned above appeared. The error message seems to only appear when I try to the move the U-Axis in increments of 50 or more, but doesn't appear when I try to move the U-Axis in increments of 10 or less.

I was wondering if there are some guidelines that I can use to troubleshoot and diagnose the source of the problem.

The Jubilee that I am operating on uses RepRapFirmware for Duet 3 Mini 5+ version 3.5.3 (2024-09-18) and is running on Duet 3 Mini5plus WiFi (SBC mode).

jzhang-03, 2025-02-03:
Motor was disconnected.

bsubbaraman, 2025-02-03:
Glad it was figured it out---thanks for posting, could be useful for others to see this error + fix on here!

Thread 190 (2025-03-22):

Duplicate section headers in pipette tool build instructions

gregory-robben, 2025-03-22:
Section headers for steps 2 and 4 of the pipette build documentation are the same.

Sections 2
https://github.com/machineagency/science-jubilee/blob/main/docs/building/pipette_tool.md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
Section 4
https://github.com/machineagency/science-jubilee/blob/main/docs/building/pipette_tool.md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

Will submit a PR to propose new step 4 header

bsubbaraman, 2025-03-25:
This didn't auto-close, but I believe that #191 addresses this! Thanks!!

Closed 2025-03-25.

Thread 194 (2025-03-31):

Pipette 'never' tip strategy doesn't work

bsubbaraman, 2025-03-31:
### Steps to reproduce this bug

When using the `new_tip='never'` tip strategy without a tip equipped, we assert that a tip needs to be attached first. When running it with a tip attached, we get an error because [there is no `tip` variable](https://github.com/machineagency/science-jubilee/blob/15e1ec85fd068f241d3ff9c46b94b127a8308b4e/src/science_jubilee/tools/Pipette.py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) for the 'never' strategy.

I can fix this in a pull request by just checking if we're using the 'never' strategy in line referenced above.

Closed 2025-03-31.

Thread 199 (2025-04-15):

Alternate to seeed?

bobthechemist, 2025-04-15:
### Feature enhancement details

One issue that came up with the AS7341 spectral sensor is how it is dependent on the microcontroller being SEEED based. (src/science_jubilee/tools/AS7341.py) Since CircuitPython is used for the microcontroller, a more generalized approach might be to use the [Adafruit board toolkit](https://docs.circuitpython.org/projects/board-toolkit/en/latest/index.html) which returns any CP-based board.

danlil666, 2025-04-15:
good suggestion! will try to implement this.

jschrier, 2025-04-18:
@bobthechemist : It would be neat to make a notional implementation with a [little RP 2040 QT board](https://www.adafruit.com/product/4900), as all this tool really needs is a STEMMA and USB ports, and it would fit more nicely into the tool package.

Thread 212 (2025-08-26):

Pipette tool doesn't attempt to pick up a tip when calling pickup_tip()

ststewa3, 2025-08-26:
### Duet3D Firmware Version

FIRMWARE_NAME: RepRapFirmware for Duet 3 Mini 5+ FIRMWARE_VERSION: 3.5.4 ELECTRONICS: Duet 3 Mini5plus Ethernet FIRMWARE_DATE: 2024-11-24 10:44:24

### Steps to reproduce this bug

### Steps:
1. Turn on and home Jubilee (including V axis)
2. Run the code snippet below
3. Pipette moves to the correct XY position, but then moves the bed down instead of up when attempting to pick up a pipette tip

### Snippet:

```python

from science_jubilee.Machine import Machine
from science_jubilee.tools.Pipette import Pipette
from science_jubilee.labware.Labware import Labware

m = Machine(address="10.155.55.214")
m.home_all()

deck = m.load_deck("lab_automation_deck_CALIBRATION_4")

# Now install labware in correct positions
m.move_to(z=150)
tiprack = m.load_labware("opentrons_96_filtertiprack_1000ul", 0)
trash = m.load_labware("generic_petri_dish_100ml", 1)
samples = m.load_labware("nest_96_wellplate_200ul_flat", 2)
stocks = m.load_labware("nest_12_reservoir_15ml", 3)

pipette_index = 1
pipette_config = "P1000_config.json"
pipette_name = "Pipette"

pipette = Pipette.from_config(pipette_index, pipette_name, pipette_config)
m.load_tool(pipette)

pipette.add_tiprack(tiprack)
pipette.trash = trash[0]

m.pickup_tool(pipette)

pipette.pickup_tip()

# Pipette moves to correct XY position, but moves the bed down instead of up to pick up a tip

```

### Notes:

- I double checked my wiring from [this tutorial](https://science-jubilee.readthedocs.io/en/latest/building/pipette_tool.html) and everything matches up
- My config.g file also follows the tutorial. I copied and pasted it at the end of this issue in case it is useful to look at.
- Pipette.py API code also matches what's currently on the Science Jubilee GitHub
- Video of the issue:

https://github.com/user-attachments/assets/55d30ca5-6329-4ffb-947f-e749bfa98751

### My config.g file:

```
; Default config.g template for DuetPi
; Replace this with a proper configuration file (e.g from https://configtool.reprapfirmware.org)

; Display initial welcome message
M291 P"You are operating an SBC image in standalone mode. Please see <a href=""https://www.duet3d.com/StartHere"" target=""_blank"">here</a> further information." R"Welcome to your new Duet 3!" S1 T0

; Enable PanelDue
M575 P1 B57600 S1

; Enable network
;M552 P0.0.0.0 S1
;-------------------------------------------------------------------------------

; Jubilee CoreXY ToolChanging Printer - Config File
; This file is intended for a Duet 3 Mini Mainboard + one 3HC expansion board.

; Name and Network
;-------------------------------------------------------------------------------
M550 P"jubileepi"           ; Name used in UI and for mDNS  http://Jubilee.local
; Networking handled by Duet.
; Comment out the next three lines only if running the Duet in SBC Mode with Pi.
;M552 P192.168.1.2 S1      ; Use Ethernet with a static IP, 0.0.0.0 for dhcp
;M554 192.168.1.3          ; Gateway
;M553 P255.255.255.0       ; Netmask

; General setup
;-------------------------------------------------------------------------------
M111 S0                    ; Debug off
M929 P"eventlog.txt" S1    ; Start logging to file eventlog.txt

; General Preferences
M555 P2                    ; Set Marlin-style output
G21                        ; Set dimensions to millimetres
G90                        ; Send absolute coordinates...
M83                        ; ...but relative extruder moves

; Motor (Drive) to Axis Mapping
;-------------------------------------------------------------------------------
M584 X1.0 Y1.1            ; Map Corexy's X,Y axes to 3HC board port's 0 and 1.
M584 U0.1                 ; Map U axis (toolchanger lock) do main board port 1.
M584 Z0.2:0.3:0.4         ; Map 3 axes for Z to main board ports 2, 3, and 4.
M584 V1.2                 ; Pipette plugged into driver 2 on the expansion board

; Motor (Drive) Currents and Directions
;-------------------------------------------------------------------------------
M569 P1.0 S1              ; Flip 3HC Motor 0 (corexy a) direction
M569 P1.1 S1              ; Flip 3HC Motor 1 (corexy b) direction
M906 X{0.85*sqrt(2)*2500} ; LDO XY 2500mA RMS the TMC5160 driver on duet3
M906 Y{0.85*sqrt(2)*2500} ; generates a sinusoidal coil current so we can
                          ; multply by sqrt(2) to get peak used for M906
                          ; Do not exceed 90% without heatsinking the XY
                          ; steppers.
                                   
M569 P0.2 S0              ; Flip Mainboard Motor 2 (Front Left Z) direction.
M569 P0.3 S0              ; Flip Mainboard Motor 2 (Front Right Z) direction.
M569 P0.4 S0              ; Flip Mainboard Motor 2 (Back Z) direction.
M906 Z{0.7*sqrt(2)*1680}  ; 70% of 1680mA RMS current.

M569 P0.1 S1              ; Flip Main Board Motor 0 (toolchanger) directon.
M906 U670 I60             ; 100% of 670mA RMS current. idle 60%.
                          ; Note that the idle will be shared for all drivers.

M569 P1.2 S0              ; Set pipette motor direction
M906 V500                 ; 500mA peak current for gen2 pipette (change to 350mA if using gen1 pipette)

; Kinematics
;-------------------------------------------------------------------------------
M669 K1                   ; CoreXY mode

; Kinematic bed ball locations.
; Locations are extracted from CAD model assuming lower left build plate corner
; is (0, 0) on a 305x305mm plate.
M671 X297.5:2.5:150 Y313.5:313.5:-16.5 S10 ; Front Left: (297.5, 313.5)
                                           ; Front Right: (2.5, 313.5)
                                           ; Back: (150, -16.5)
                                           ; Set up to 10mm correction.

; Steps/<unit> Configuration
; XYZZZ are in steps/mm. U is in steps/degree.
;-------------------------------------------------------------------------------

M92 V200               ; Microstepping for a gen2 single channel pipette (put
                       ; before other M92 commands since it messes with motor
                       ; settings if you don't)

M350 X1 Y1 Z1 U1       ; Disable microstepping to simplify calculations.
M92 X{1/(1.8*16/180)}  ; step angle * tooth count / 180 .
M92 Y{1/(1.8*16/180)}  ; The 2mm tooth spacing cancel out with diam to radius.
M92 Z{360/0.9/4}       ; 0.9 deg stepper / screw lead pitch (4mm) .
                       ; If using a T8x2 leadscrew, change 4 to 2.
M92 U{13.76/1.8}       ; gear ratio / step angle for tool lock geared motor.

; Enable microstepping.
; All steps-per-unit will be multiplied by the new step definition.
M350 X16 Y16 I1        ; 16x microstepping for CoreXY axes. Use interpolation.
M350 U4 I1             ; 4x for toolchanger lock. Use interpolation.
M350 Z16 I1            ; 16x microstepping for Z axes. Use interpolation.

M350 V16 I1            ; Set pipette microstepping after M92 command

; Speed and Acceleration
;-------------------------------------------------------------------------------
M201 X1500 Y1500       ; XY accelerations [mm/s^2]
                       ; XY accel can be increased up to 2500 or beyond later.
M201 Z100              ; ZZZ Acceleration
M201 U800              ; U accelerations [deg/s^2]

M203 X18000 Y18000 Z1600 U9000 ; Maximum axis speeds [mm/min]
                               ; If using a T8x2 leadscrew, change Z to 800.
M566 X500 Y500 Z500 U50        ; Maximum jerk speeds [mm/min]

M201 V800              ; Max acceleration for V (pipette) axis
M203 V10000            ; Max speed for V axis
M566 V4000             ; Max jerk for V axis

; Endstops and Probes
;-------------------------------------------------------------------------------
M574 X1 S1 P"^1.io0.in"  ; 3HC X homing position X1 = axis min, S1 = switch type
M574 Y1 S1 P"^1.io1.in"  ; 3HC Y homing position Y1 = axis min, S1 = switch type
M574 U1 S1 P"^0.io1.in"  ; Mainboard U homing position.
                         ; U1 = axis min, S1 = switch type

M574 Z0                  ; Configure z switch as a Z probe, not as an endstop.

M574 V1 S1 P"^0.io3.in"  ; Pipette endstop plugged into io3 on main board
M574 Z1 P"^0.io2.in"     ; Pipette tip pick up endstop plugged into io2 on main board

M558 P8 C"io0.in" H3 F360 T6000 ; H = dive height
                                ; F = probe speed
                                ; T = travel speed
G31 K0 X0 Y0 Z-2        ; Set the limit switch as the "Control Point"
                        ; Offset it downwards slightly so we don't smear it along
                        ; the bed while traveling when z=0.

; Set axis software limits and min/max switch-triggering positions.
; Dimensions are adjusted such that (0,0) lies at the lower left corner
; of a centered 300x300mm square in the 305mmx305mm build plate.
M208 X-13.75:313.75 Y-44:341 Z0:300
M208 U0:200            ; Set Elastic Lock (U axis) max rotation angle

; Bed Heater and Temperature Sensor
;-------------------------------------------------------------------------------
; Define Built-in Thermistor Settings
M308 S0 P"temp0" Y"thermistor" T100000 B3950 A"Bed" ; built-in Keenovo thermistor
; Define Heater 0
M950 H0 C"out0" T0      ; H = Heater 0
                        ; C = heater output pin
                        ; T = assigned temperature sensor
M143 H0 S130            ; Set max bed temperature to 130C
M140 H0                 ; Assign Heater 0 to the bed

; This config requires a heater-tuning procedure to produce a valid M307 command.

; Tool Definitions
;-------------------------------------------------------------------------------
M563 P0 S"Camera"          ; Camera with tool index 0
M950 P0 C"0.out5"          ; Camera LED lights with LED index 0
M563 P1 S"P1000 Pipette"   ; Pipette with tool index 1
M563 P2 S"Spectrometer"    ; Spectrometer with tool index 2

M98  P"/sys/toffsets.g" ; Load tool offsets from the Control Point from ext file.
M501                    ; Load saved parameters from config-override.g
```

bsubbaraman, 2025-08-26:
Hi @ststewa3! It looks to me like the system thinks the endstop is already engaged when starting the pickup, and is moving immediately to a `safe_z` position. Is the pipette pickup endstop working as expected? If you check the endstop status (e.g. with an `M119` commands sent from the duet web console), is the Z endstop disabled before pickup? And if you manually engage the pipette endstop and hold it while sending the `M119` command again, is it enabled?

Let me know what you find, or I can follow up with more info!

ststewa3, 2025-08-26:
Hi @bsubbaraman, it says that the V axis is not stopped when the limit switch is pressed and not pressed. I also checked the switch with a multimeter and there is no difference in resistance when the switch is pressed or not pressed. I guess there's just a bad connection so I'll replace the switch and see if that helps.

bsubbaraman, 2025-09-27:
Great, thanks for letting me know how it went! Happy pipetting 🧪

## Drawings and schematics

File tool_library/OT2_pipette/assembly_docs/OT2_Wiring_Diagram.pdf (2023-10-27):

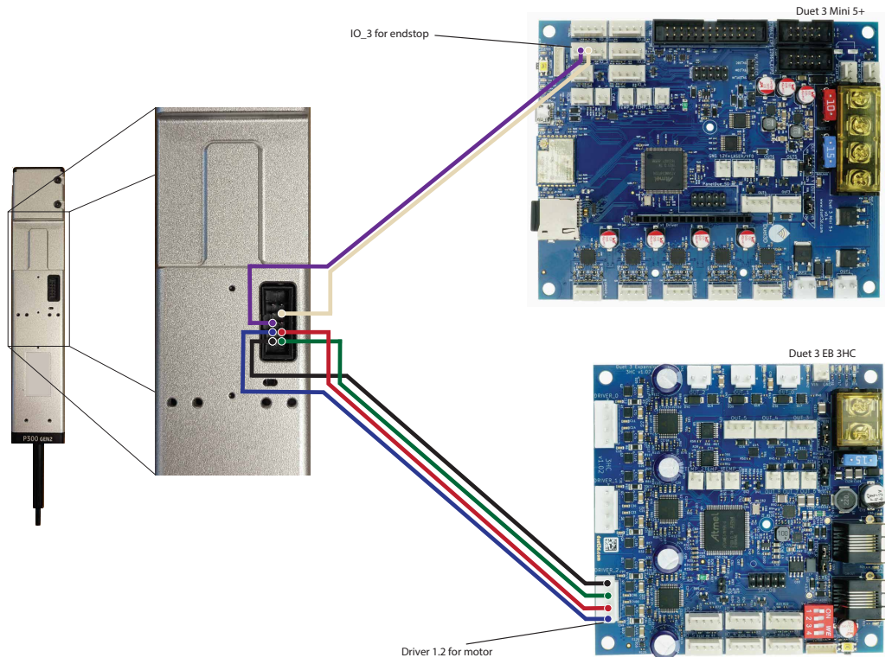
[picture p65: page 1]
Duet 3 Mini 5+; Duet 3 EB 3HC; IO_3 for endstop

Driver 1.2 for motor

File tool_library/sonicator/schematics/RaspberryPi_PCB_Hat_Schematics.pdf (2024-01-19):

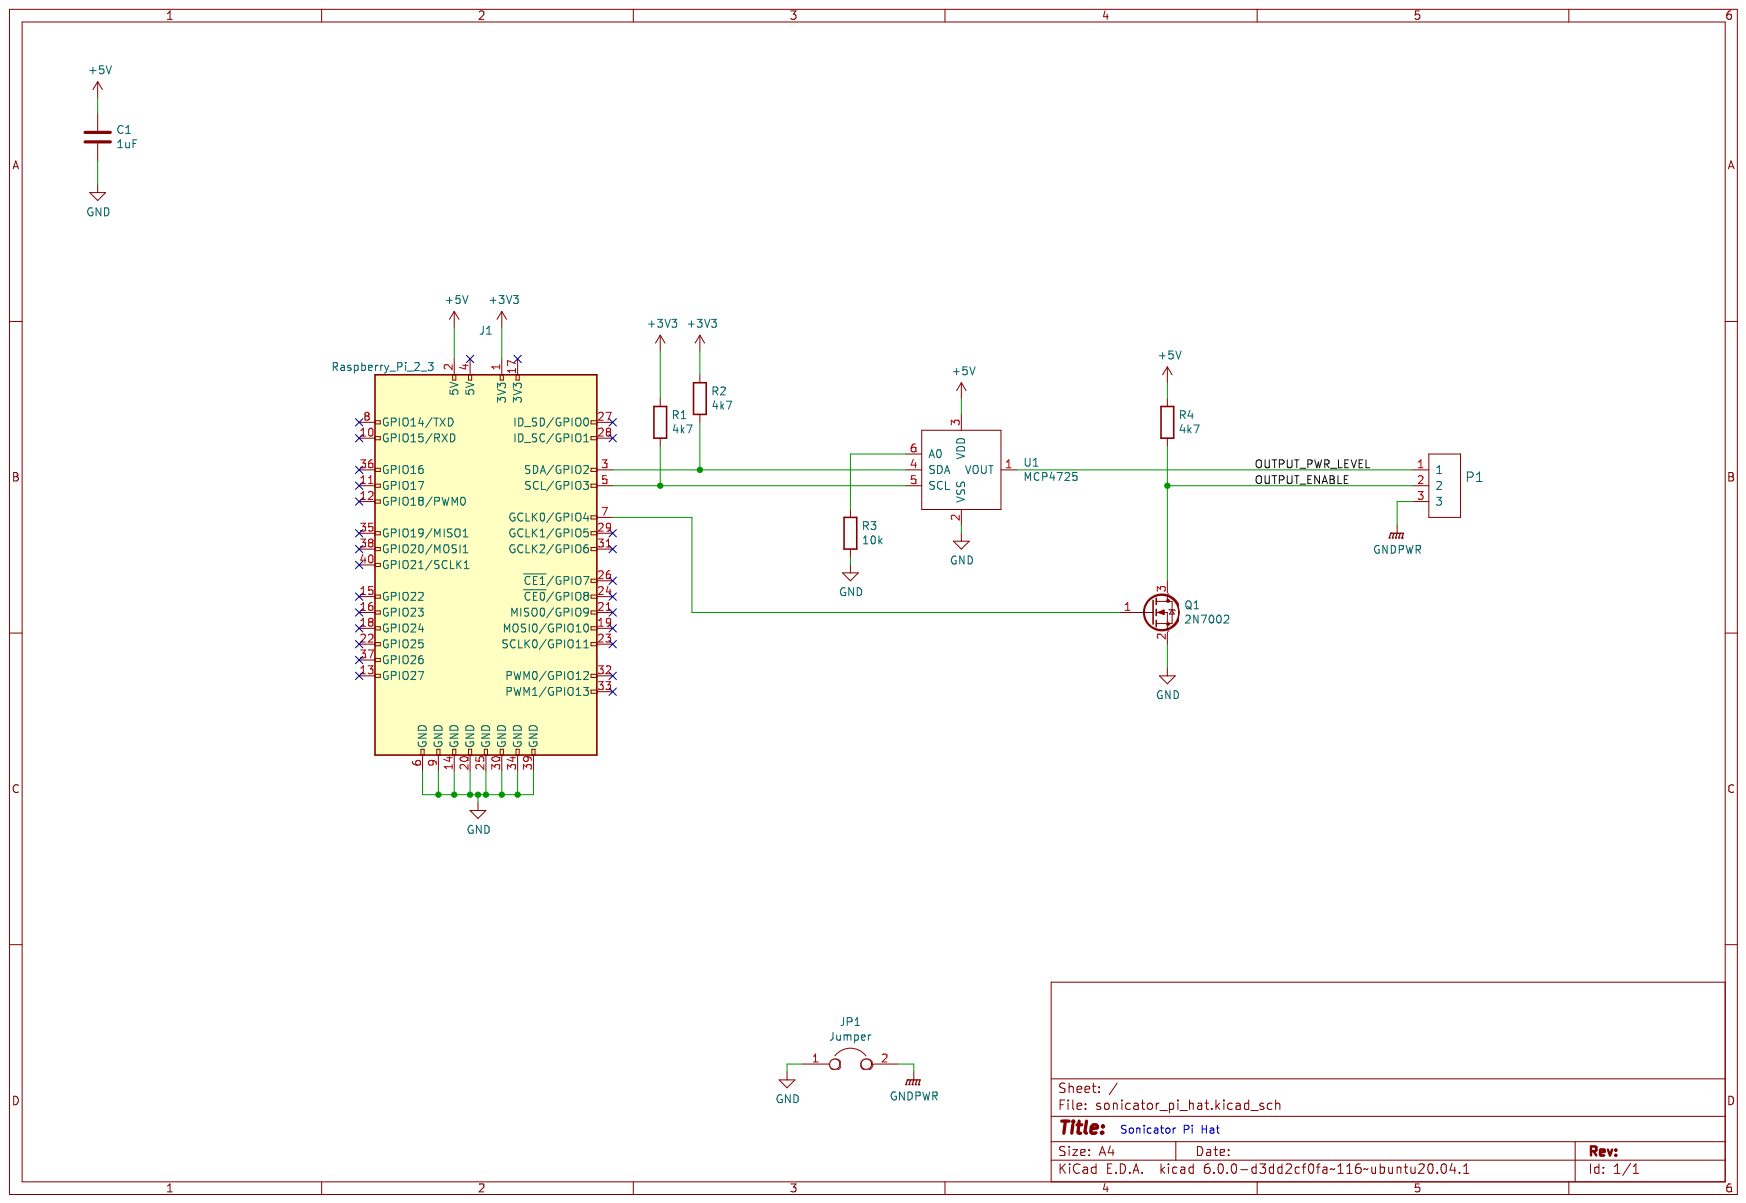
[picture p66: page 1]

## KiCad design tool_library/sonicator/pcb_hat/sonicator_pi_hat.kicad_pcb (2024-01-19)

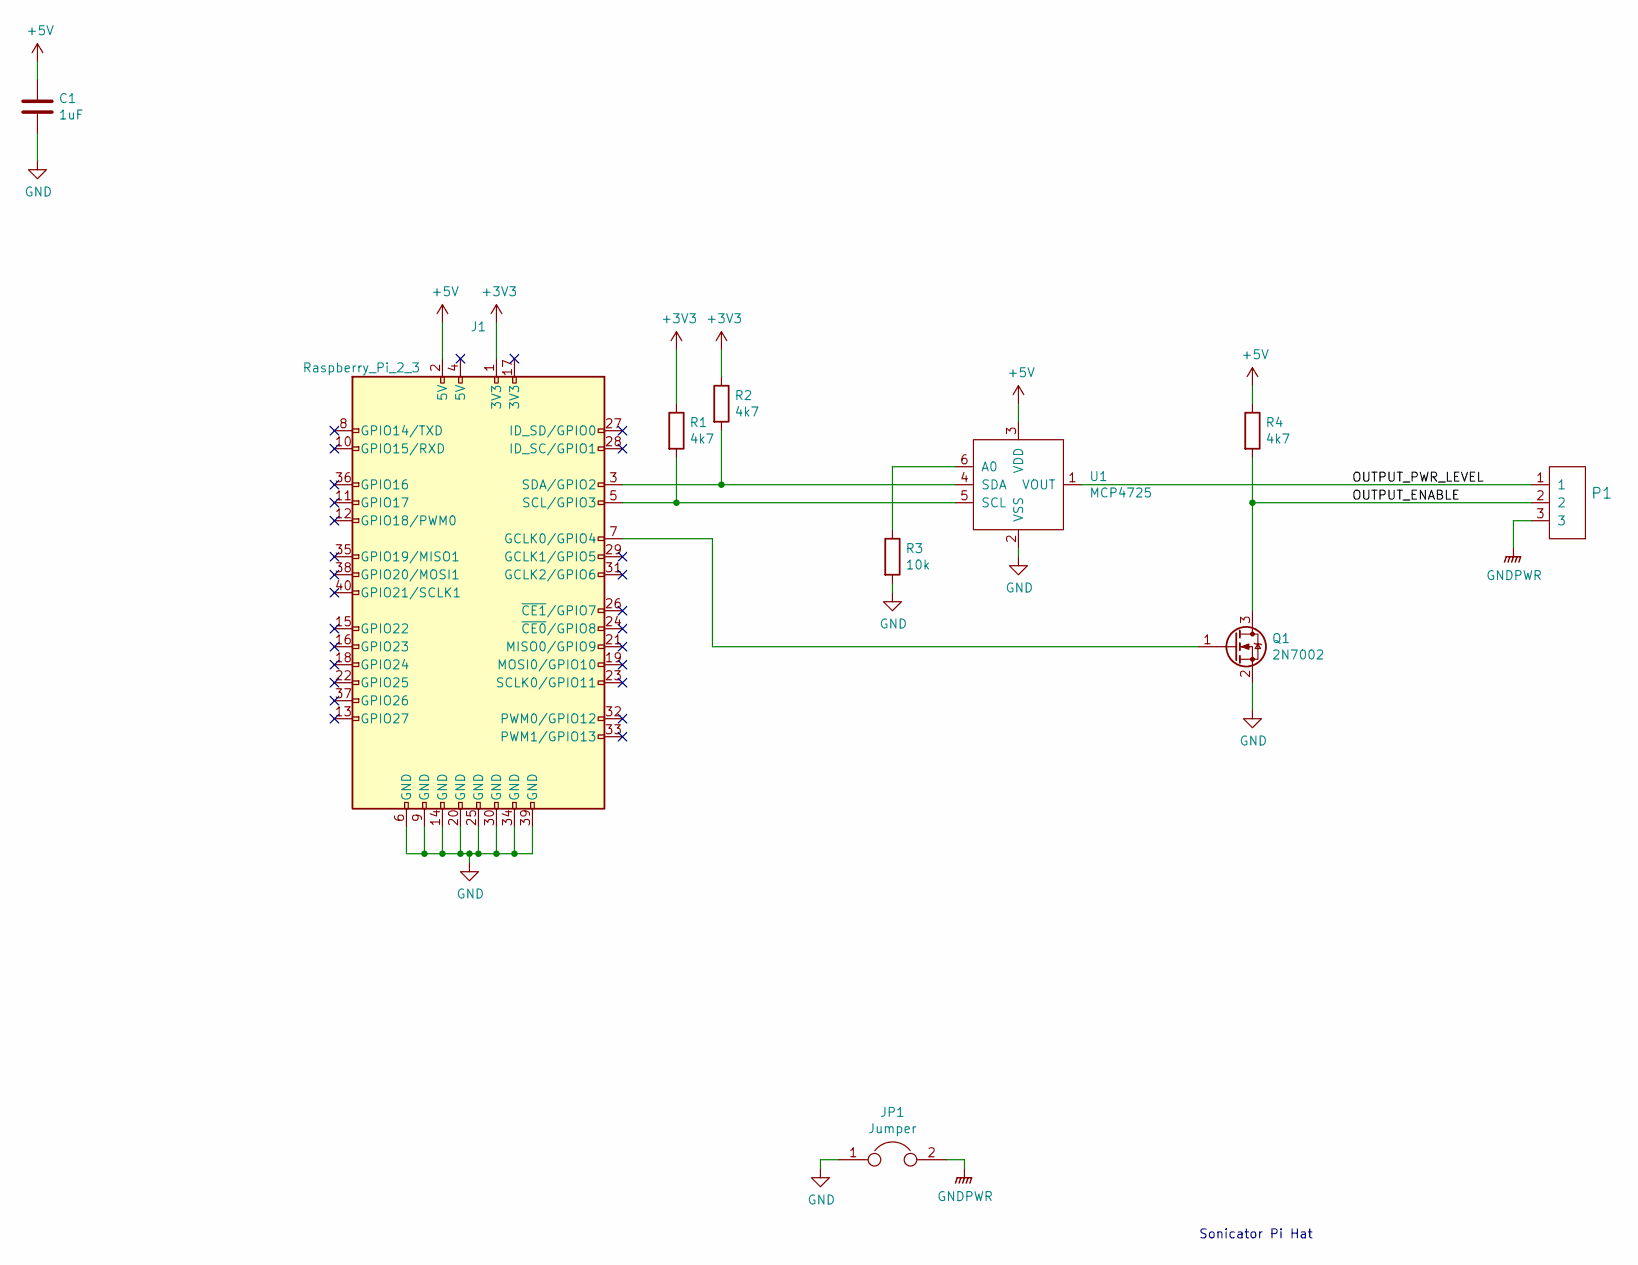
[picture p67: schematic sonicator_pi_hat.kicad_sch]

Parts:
C1: 1uF; C_0603_1608Metric
J1: Raspberry_Pi_2_3; PinHeader_2x20_P2.54mm_Vertical
JP1: Jumper; SolderJumper-2_P1.3mm_Bridged_Pad1.0x1.5mm
P1: 3pos_terminal_block; TerminalBlock_Phoenix_MPT-0,5-3-2.54_1x03_P2.54mm_Horizontal
Q1: 2N7002; SOT-23
R1, R2, R4: 4k7; R_0603_1608Metric_Pad1.05x0.95mm_HandSolder
R3: 10k; R_0603_1608Metric_Pad1.05x0.95mm_HandSolder
U1: MCP4725; TSOP-6_1.65x3.05mm_P0.95mm

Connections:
+3V3: J1.1 (3V3), R1.1, R2.1
+5V: C1.1, J1.2 (5V), R4.1, U1.3 (VDD)
/OUTPUT_ENABLE: P1.2, Q1.3 (D), R4.2
/OUTPUT_PWR_LEVEL: P1.1, U1.1 (VOUT)
GND: C1.2, J1.6 (GND), J1.9 (GND), J1.14 (GND), J1.20 (GND), J1.25 (GND), J1.30 (GND), J1.34 (GND), J1.39 (GND), JP1.1, Q1.2 (S), R3.2, U1.2 (VSS)
GNDPWR: JP1.2, P1.3
unnamed: J1.3 (SDA/GPIO2), R2.2, U1.4 (SDA)
unnamed: J1.5 (SCL/GPIO3), R1.2, U1.5 (SCL)
unnamed: J1.7 (GCLK0/GPIO4), Q1.1 (G)
unnamed: R3.1, U1.6 (A0)

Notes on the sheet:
Sonicator Pi Hat

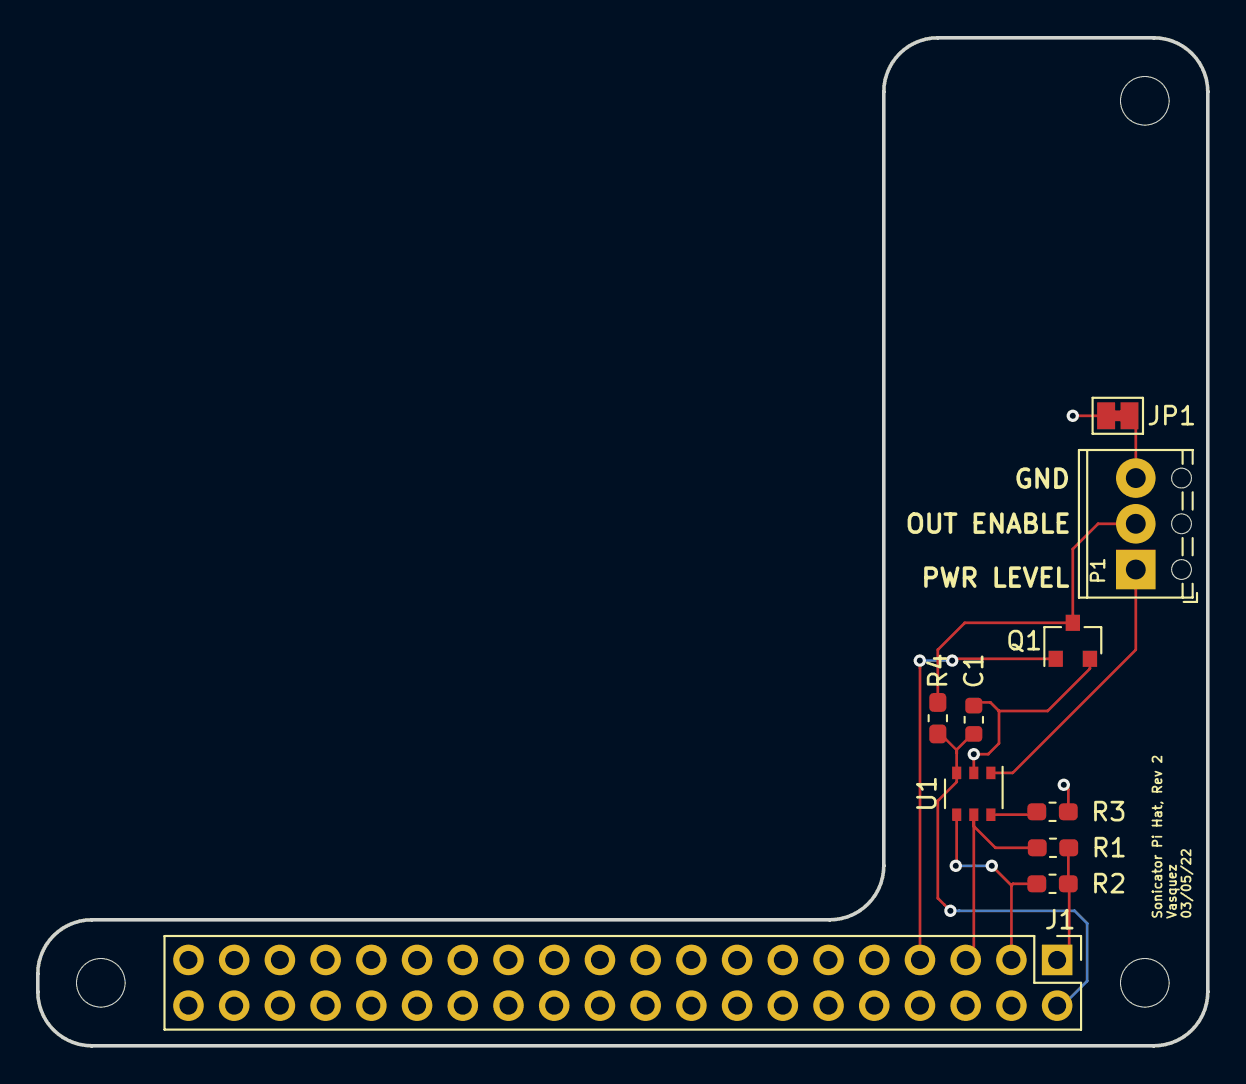
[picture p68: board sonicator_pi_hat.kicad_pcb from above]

Board: 2 copper layers, 65.0 x 56.0 mm, 10 parts (0 on the bottom side), 10 nets.

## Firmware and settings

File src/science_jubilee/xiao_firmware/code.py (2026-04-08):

"""
code.py - Main Loop & Command Handling
Runs continuously on XIAO ESP32S3

This file:
1. Sets up JSON-RPC communication protocol
2. Registers all available commands
3. Executes commands and returns structured responses
"""

import time
import json
import usb_cdc
from boot import hardware

# USB CDC setup
serial = usb_cdc.console
serial.timeout = 1

# ============================================================================
# Command Registry
# ============================================================================

class CommandRegistry:
    """Registry for all available commands."""
    
    def __init__(self, hw):
        self.hw = hw
        self.commands = {}
    
    def register(self, name, handler, params_schema=None, description=""):
        """Register a command handler."""
        self.commands[name] = {
            'handler': handler,
            'params': params_schema or {},
            'description': description
        }
    
    def execute(self, method, params):
        """Execute a command and return result."""
        if method not in self.commands:
            return {
                'success': False,
                'error': f'Unknown command: {method}',
                'available': list(self.commands.keys())
            }
        
        try:
            result = self.commands[method]['handler'](params)
            if not isinstance(result, dict):
                result = {'value': result}
            result.setdefault('success', True)
            return result
        except Exception as e:
            return {
                'success': False,
                'error': str(e),
                'error_type': type(e).__name__
            }
    
    def get_commands_info(self):
        """Get information about all commands."""
        return {
            name: {
                'params': cmd['params'],
                'description': cmd['description']
            }
            for name, cmd in self.commands.items()
        }

# ============================================================================
# Command Handlers
# ============================================================================

def cmd_get_capabilities(params):
    """Return complete system capabilities."""
    caps = hardware.get_capabilities()
    caps['commands'] = commands.get_commands_info()
    return {'success': True, 'capabilities': caps}

def cmd_blink(params):
    """Blink onboard LED."""
    duration = float(params.get('duration', 0.5))
    led = hardware.get_actuator('onboard_led')
    
    if not led:
        return {'success': False, 'error': 'LED not available'}
    
    led.value = False
    time.sleep(duration)
    led.value = True
    
    return {'success': True, 'duration': duration}

def cmd_set_motor(params):
    """Set DC motor throttle."""
    motor_name = params.get('motor')
    throttle = int(params.get('throttle', 0))
    
    if not motor_name:
        return {'success': False, 'error': 'motor parameter required'}
    
    motor = hardware.get_actuator(motor_name)
    if not motor:
        return {
            'success': False,
            'error': f'Motor {motor_name} not available',
            'available': [n for n in hardware.actuators.keys() if 'motor' in n]
        }
    
    if not -100 <= throttle <= 100:
        return {'success': False, 'error': 'throttle must be -100 to 100'}
    
    motor.throttle = throttle / 100.0
    return {'success': True, 'motor': motor_name, 'throttle': throttle}

def cmd_pump(params):
    """Run pump for specified duration."""
    motor_name = params.get('motor')
    duration = params.get('duration')
    throttle = int(params.get('throttle', 100))
    
    if not motor_name or duration is None:
        return {'success': False, 'error': 'motor and duration required'}
    
    motor = hardware.get_actuator(motor_name)
    if not motor:
        return {'success': False, 'error': f'Motor {motor_name} not available'}
    
    # Run pump
    motor.throttle = throttle / 100.0
    time.sleep(float(duration))
    motor.throttle = 0
    
    return {
        'success': True,
        'motor': motor_name,
        'duration': float(duration),
        'throttle': throttle
    }

def cmd_stop_motor(params):
    """Stop one or all motors."""
    motor_name = params.get('motor', 'all')
    
    if motor_name == 'all':
        stopped = []
        for name, info in hardware.actuators.items():
            if 'motor' in name and hasattr(info['instance'], 'throttle'):
                info['instance'].throttle = 0
                stopped.append(name)
        return {'success': True, 'stopped': stopped}
    else:
        motor = hardware.get_actuator(motor_name)
        if not motor:
            return {'success': False, 'error': f'{motor_name} not found'}
        if hasattr(motor, 'throttle'):
            motor.throttle = 0
            return {'success': True, 'motor': motor_name}
        return {'success': False, 'error': f'{motor_name} is not a motor'}

def cmd_read_sensor(params):
    """Read from a sensor."""
    sensor_name = params.get('sensor')
    
    if not sensor_name:
        return {
            'success': False,
            'error': 'sensor parameter required',
            'available': list(hardware.sensors.keys())
        }
    
    sensor = hardware.get_sensor(sensor_name)
    if not sensor:
        return {
            'success': False,
            'error': f'Sensor {sensor_name} not available',
            'available': list(hardware.sensors.keys())
        }
    
    # Route to appropriate reader
    if sensor_name == 'as7341':
        return read_spectrometer(sensor, params)
    elif sensor_name == 'scd4x':
        return read_scd4x(sensor, params)
    elif sensor_name == 'vl53l0x':
        return read_distance(sensor, params)
    else:
        return {'success': False, 'error': f'No handler for {sensor_name}'}

def read_spectrometer(sensor, params):
    """Read AS7341 spectrometer."""
    led_current = int(params.get('led_current', 10))

    # Turn on AS7341's onboard white LED
    sensor.led_current = led_current  # mA (4-258)
    sensor.led = True
    time.sleep(0.1)

    # Read all channels
    readings = {
        '415nm': sensor.channel_415nm,
        '445nm': sensor.channel_445nm,
        '480nm': sensor.channel_480nm,
        '515nm': sensor.channel_515nm,
        '555nm': sensor.channel_555nm,
        '590nm': sensor.channel_590nm,
        '630nm': sensor.channel_630nm,
        '680nm': sensor.channel_680nm
    }

    # Turn off LED
    sensor.led = False

    return {
        'success': True,
        'sensor': 'as7341',
        'led_current': led_current,
        'readings': readings
    }

def read_scd4x(sensor, params):
    """Read SCD4x environmental sensor."""
    if not sensor.data_ready:
        sensor.measure_single_shot()
        time.sleep(5)
    
    if sensor.data_ready:
        return {
            'success': True,
            'sensor': 'scd4x',
            'readings': {
                'co2_ppm': sensor.CO2,
                'temperature_c': sensor.temperature,
                'humidity_percent': sensor.relative_humidity
            }
        }
    return {'success': False, 'error': 'Sensor data not ready'}

def read_distance(sensor, params):
    """Read VL53L0X distance sensor."""
    return {
        'success': True,
        'sensor': 'vl53l0x',
        'readings': {
            'distance_mm': sensor.range
        }
    }

def cmd_capture_image(params):
    """Capture a JPEG image from the OV2640 camera.

    Returns the image as a base64-encoded string inside the JSON response.
    For QQVGA (160x120) this is typically 3–12 KB of base64 and transfers
    in under 2 seconds at 115200 baud. Increase module.timeout for larger
    resolutions on the host side.
    """
    import binascii

    cam = hardware.get_sensor('camera')
    if not cam:
        return {'success': False, 'error': 'Camera not available'}

    # frame_size is set at init time in the camera driver (drivers/camera.py).
    # Resolution is fixed until the firmware is reflashed.
    frame = cam.take(1)
    if frame is None:
        return {'success': False, 'error': 'Failed to capture frame'}

    encoded = binascii.b2a_base64(bytes(frame)).decode('ascii').strip()

    return {
        'success': True,
        'format': 'jpeg',
        'encoding': 'base64',
        'width': cam.width,
        'height': cam.height,
        'size_bytes': len(frame),
        'data': encoded,
    }


def cmd_set_led(params):
    """Set external blue LED intensity."""
    intensity = float(params.get('intensity', 0))

    blue_led = hardware.get_actuator('blue_led')
    if not blue_led:
        return {'success': False, 'error': 'LED not available'}

    if not 0 <= intensity <= 1:
        return {'success': False, 'error': 'intensity must be 0-1'}

    blue_led.duty_cycle = int(intensity * 65535)
    return {'success': True, 'intensity': intensity}

def cmd_set_sensor_led(params):
    """Set AS7341 onboard white LED."""
    current = int(params.get('current', 0))

    sensor = hardware.get_sensor('as7341')
    if not sensor:
        return {'success': False, 'error': 'AS7341 not available'}

    if current == 0:
        sensor.led = False
        return {'success': True, 'led': False, 'current': 0}

    if not 4 <= current <= 258:
        return {'success': False, 'error': 'current must be 0 (off) or 4-258 mA'}

    sensor.led_current = current
    sensor.led = True
    return {'success': True, 'led': True, 'current': current}

def cmd_get_property(params):
    """Get any property from a registered sensor."""
    sensor_name = params.get('sensor')
    prop = params.get('property')

    if not sensor_name or not prop:
        return {'success': False, 'error': 'sensor and property required'}

    sensor = hardware.get_sensor(sensor_name)
    if not sensor:
        return {'success': False, 'error': f'Sensor {sensor_name} not available'}

    try:
        value = getattr(sensor, prop)
        if isinstance(value, tuple):
            value = list(value)
        elif not isinstance(value, (int, float, bool, str, list, type(None))):
            return {'success': False, 'error': f'{prop} returned non-serializable type: {type(value).__name__}'}
        return {'success': True, 'property': prop, 'value': value}
    except AttributeError:
        return {'success': False, 'error': f'{prop} not found on {sensor_name}'}
    except Exception as e:
        return {'success': False, 'error': str(e)}

def cmd_set_property(params):
    """Set any property on a registered sensor."""
    sensor_name = params.get('sensor')
    prop = params.get('property')
    value = params.get('value')

    if not sensor_name or not prop:
        return {'success': False, 'error': 'sensor, property, and value required'}

    sensor = hardware.get_sensor(sensor_name)
    if not sensor:
        return {'success': False, 'error': f'Sensor {sensor_name} not available'}

    try:
        setattr(sensor, prop, value)
        return {'success': True, 'property': prop, 'value': value}
    except AttributeError:
        return {'success': False, 'error': f'{prop} is read-only on {sensor_name}'}
    except Exception as e:
        return {'success': False, 'error': str(e)}

# ============================================================================
# Register All Commands
# ============================================================================

commands = CommandRegistry(hardware)

commands.register('get_capabilities', cmd_get_capabilities,
                 params_schema={},
                 description='Get system capabilities and available commands')

commands.register('blink', cmd_blink,
                 params_schema={'duration': 'float (seconds)'},
                 description='Blink onboard LED')

commands.register('set_motor', cmd_set_motor,
                 params_schema={
                     'motor': 'string (motor name)',
                     'throttle': 'int (-100 to 100)'
                 },
                 description='Set DC motor throttle')

commands.register('pump', cmd_pump,
                 params_schema={
                     'motor': 'string (motor name)',
                     'duration': 'float (seconds)',
                     'throttle': 'int (0-100, default 100)'
                 },
                 description='Run pump for duration')

commands.register('stop_motor', cmd_stop_motor,
                 params_schema={'motor': 'string (name or "all")'},
                 description='Stop motor(s)')

commands.register('read_sensor', cmd_read_sensor,
                 params_schema={
                     'sensor': 'string (sensor name)',
                     'led_intensity': 'float (0-1, for spectrometer)'
                 },
                 description='Read from sensor')

commands.register('set_led', cmd_set_led,
                 params_schema={'intensity': 'float (0-1)'},
                 description='Set external blue LED intensity')

commands.register('set_sensor_led', cmd_set_sensor_led,
                 params_schema={'current': 'int (0=off, 4-258 mA)'},
                 description='Set AS7341 onboard white LED')

commands.register('capture_image', cmd_capture_image,
                 params_schema={},
                 description='Capture a JPEG image from the OV2640 camera, returned as base64')

commands.register('get_property', cmd_get_property,
                 params_schema={'sensor': 'string', 'property': 'string'},
                 description='Get any property from a sensor')

commands.register('set_property', cmd_set_property,
                 params_schema={'sensor': 'string', 'property': 'string', 'value': 'any'},
                 description='Set any property on a sensor')

# ============================================================================
# Protocol Handler
# ============================================================================

def parse_request(line_str):
    """Parse incoming request (JSON-RPC only)."""
    try:
        request = json.loads(line_str)
        return (
            request.get('method'),
            request.get('params', {}),
            request.get('id')
        )
    except:
        return None, None, None

def send_response(result, request_id=None):
    """Send JSON-RPC response."""
    response = {
        'jsonrpc': '2.0',
        'id': request_id
    }
    
    if result.get('success', True):
        response['result'] = result
    else:
        response['error'] = {
            'message': result.get('error', 'Unknown error'),
            'data': result
        }
    
    print(json.dumps(response))

# ============================================================================
# Main Loop
# ============================================================================

print("Bioreactor firmware ready!")
print(f"Available commands: {list(commands.commands.keys())}\n")

while True:
    if serial.in_waiting > 0:
        try:
            line = serial.readline()
            if not line or line in (b'\r', b'\n'):
                continue
            
            line_str = line.decode('utf-8').strip()
            if not line_str:
                continue
            
            # Parse request
            method, params, request_id = parse_request(line_str)
            
            if method is None:
                send_response({
                    'success': False,
                    'error': 'Invalid JSON-RPC request'
                }, request_id)
                continue
            
            # Execute command
            result = commands.execute(method, params)
            
            # Send response
            send_response(result, request_id)
            
        except Exception as e:
            send_response({
                'success': False,
                'error': str(e),
                'error_type': type(e).__name__
            })

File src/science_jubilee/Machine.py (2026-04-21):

"""Driver for Controlling Jubilee"""

# import websocket # for reading the machine model

import json
import logging
import os
import re
import time
import warnings
from functools import wraps
from pathlib import Path
from typing import Union

import requests  # for issuing commands
from requests.adapters import HTTPAdapter, Retry

from science_jubilee.decks.Deck import Deck
from science_jubilee.tools.Tool import Tool

# TODO: Figure out how to print error messages from the Duet.

logger = logging.getLogger(__name__)
# copied from machine agency version, may not be needed here


def get_root_dir():
    """Return the path to the duckbot directory."""
    return Path(__file__).parent.parent


##########################################
#               ERRORS
##########################################
class MachineConfigurationError(Exception):
    """Raise this error if there is something wrong with how the machine is configured"""

    pass


class MachineStateError(Exception):
    """Raise this error if the machine is in the wrong state to perform the requested action."""

    pass


##########################################
#               DECORATORS
##########################################
def machine_homed(func):
    """Decorator used to check if the machine is homed before performing certain actions."""

    def homing_check(self, *args, **kwds):
        # Check the cached value if one exists.
        if self.simulated:
            return func(self, *args, **kwds)
        if self.axes_homed and all(self.axes_homed):
            return func(self, *args, **kwds)
        # Request homing status from the object model if not known.
        self.axes_homed = json.loads(self.gcode('M409 K"move.axes[].homed"'))["result"]
        if not all(self.axes_homed):
            raise MachineStateError("Error: machine must first be homed.")
        return func(self, *args, **kwds)

    return homing_check


def requires_deck(func):
    """Decorator used ot check if a deck has been configured before performing certain actions."""

    def deck_check(self, *args, **kwds):
        if self.deck is None:
            raise MachineStateError("Error: No deck is set up")
        return func(self, *args, **kwds)

    return deck_check


def requires_safe_z(func):
    """Decorator used to ensure the deck is at a safe height before performing certain actions."""

    def z_check(self, *args, **kwds):
        current_z = float(self.get_position()["Z"])
        if self.deck:
            safe_z = self.deck.safe_z
        else:
            safe_z = 0
            # warnings.warn(f"No deck configured, safe z height has been set to {safe_z}. Please modify this if needed.")
        if current_z < safe_z:
            self.move_to(z=safe_z + 20)
        return func(self, *args, **kwds)

    return z_check


##########################################
#             MACHINE CLASS
##########################################


class Machine:
    """A class representation of Jubilee used to send  motion commands and polling the machine state."""

    # TODO: Set this up so that a keyboard interrupt leaves the machine in a safe state - ie tool offsets correct. I had an issue
    # where I keyboard interrupted during pipette tip pickup - tip was picked up but offset was not applied, crashing machine on next move. This should not be possible.

    LOCALHOST = "192.168.1.2"

    def __init__(
        self,
        port: str = None,
        baudrate: int = 115200,
        address: str = None,
        deck_config: str = None,
        simulated: bool = False,
        crash_detection: bool = False,
        crash_handler=None,
    ):
        """Initialize the Machine object.

        :param port: The port to connect to the machine over serial, defaults to None
        :type port: str, optional
        :param baudrate: The baudrate to use when connecting to the machine, defaults to 115200
        :type baudrate: int, optional
        :param address: The IP address of the machine. This should match what is loaded onto the config.g on the Jubilee Duet's main board, defaults to None
        :type address: str, optional
        :param deck_config: The name of the deck configuration file to load, defaults to None
        :type deck_config: str, optional
        :param simulated: Whether to simulate the machine, defaults to False
        :type simulated: bool, optional
        :param crash_detection: Whether to monitor for tool changer crash detection. See science-jubilee docs for more. Default to False (no detection)
        :type crash_detection: bool
        :param crash_handler: Function to call when crash is detected. See docs
        :type crash_handler: None or function

        :raises MachineStateError: If the machine is not in the correct state to perform the requested action. This is a user error, not a machine error.
        :raises MachineConfigurationError: If the machine does nto support the indicated configuration, e.g., a tool index is already in use.
        :raises ValueError: If Jubilee returns an invalid value, e.g., the axis limit queried is not correct or query is unsuccessful.

        """
        if address != self.__class__.LOCALHOST:
            print("Connected!")
        # Machine Specs

        # serial info
        self.ser = None
        self.port = port
        self.baudrate = baudrate
        self.lineEnding = "\n"  # serial stuff

        # HTTP info
        self.address = address

        # self.debug = debug
        self.simulated = simulated
        self.model_update_timestamp = 0
        self.command_ws = None
        self.wake_time = None  # Next scheduled time that the update thread updates.

        # crash detection
        self.crash_detection = crash_detection
        self.crash_handler = crash_handler

        self._absolute_positioning = True
        self._absolute_extrusion = (
            True  # Extrusion positioning is set separately from other axes
        )
        self._configured_axes = None
        self._configured_tools = None
        self._active_tool_index = None  # Cached value under the @property.
        self._tool_z_offsets = None  # Cached value under the @property.
        self._axis_limits = (None, None, None)  # Cached value under the @property.
        self.axes_homed = [
            False
        ] * 4  # We have at least X/Y/Z/U axes to home. Additional axes handled below in connect()
        self.deck = None
        # TODO: this is confusingly named
        self.tools = {}  # this is the list of available tools
        self.tool = None  # this is the current active tool
        self.current_well = None

        requests_session = requests.Session()
        retries = Retry(
            total=5, backoff_factor=0.1, status_forcelist=[500, 502, 503, 504]
        )

        requests_session.mount("http://", HTTPAdapter(max_retries=retries))
        requests_session.headers["Connection"] = "close"
        self.session = requests_session
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

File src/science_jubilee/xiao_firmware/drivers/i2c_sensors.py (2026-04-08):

import board
import busio


def register(hw):
    """Initialize and register all I2C sensors."""
    try:
        i2c = busio.I2C(board.D5, board.D4)  # D5=SCL(GPIO6), D4=SDA(GPIO5)
    except Exception as e:
        print(f"✗ I2C init failed: {e}")
        return

    # Try AS7341 Spectrometer
    try:
        from adafruit_as7341 import AS7341
        spec = AS7341(i2c)
        hw.register_sensor('as7341', spec, {
            'type': 'spectrometer',
            'channels': ['415nm', '445nm', '480nm', '515nm',
                       '555nm', '590nm', '630nm', '680nm'],
            'interface': 'i2c'
        })
    except (ImportError, RuntimeError, OSError):
        print("✗ AS7341 not found")

    # Try SCD4x CO2/Temperature/Humidity sensor
    try:
        import adafruit_scd4x
        scd = adafruit_scd4x.SCD4X(i2c)
        scd.start_periodic_measurement()
        hw.register_sensor('scd4x', scd, {
            'type': 'environmental',
            'measurements': ['co2_ppm', 'temperature_c', 'humidity_percent'],
            'interface': 'i2c'
        })
    except (ImportError, RuntimeError, OSError):
        print("✗ SCD4x not found")

    # Try VL53L0X Distance sensor
    try:
        import adafruit_vl53l0x
        vl = adafruit_vl53l0x.VL53L0X(i2c)
        hw.register_sensor('vl53l0x', vl, {
            'type': 'distance',
            'range_mm': [30, 1000],
            'interface': 'i2c'
        })
    except (ImportError, RuntimeError, OSError):
        print("✗ VL53L0X not found")

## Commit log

2023-08-09 first pass at repo organization
    [50mL_left_tool_wing.STL, 50mL_right_tool_wing.STL, 50mL_tool_wings.SLDPRT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]
2023-08-14 Added files for Labware, Decks, Pipette Tool and some config files. Motion controller funcitons were also added as an additional file
2023-08-15 Fixed import and broken functions"
    [Pipette.py]
2023-08-16 Updated pipette functions and Jubilee controller functions. Removed old files from name change
2023-08-17 Changed module name and fixed issues with empty gcode response upon machine startup
    [Machine.py]
2023-08-17 Fixed relative path default location for definitions and config files
    [Pipette.py, Tool.py]
2023-08-17 Added new labware for use in the demo
    [agilent_1_reservoir_290ml.json]
2023-08-19 fixed typos and several action functions for pipette use
    [Pipette.py]
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2023-08-19 added new labware to use as pipette trash
    [agilent_1_reservoir_290ml.json]
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2023-08-24 add pipette design files & docs
    [PipetteTool.3dm]
2023-08-30 edit pickup_tool to work with tool index, name, or reference; update pipette and associated configuration expectations
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2023-09-01 fix deck calibration tempate
    [Machine.py]
2023-09-01 fix labware alignment; add 24 well plate definition
2023-09-05 changed module name and combined image processing functios into camera class
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2023-09-14 work on syringe module; update default Tool functions; various other Machine fixes
    [Loop.py, Machine.py, Syringe.py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]
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2023-09-27 Partial work to merge machine agency and pozzo group pipette.py and affiliated config and base files. Incomplete.
2023-09-28 Consolidated Pipette modules into one and fixed some mire issues in functions
    [Pipette.py]
2023-09-28 fixed impports and removed dependency from Utils.py
    [Pipette.py]
2023-09-28 fixed imports, removed dependence form Utils.py
    [Machine.py]
2023-09-29 extensive debugging and hacks to get deck/labware and Pipette tool working. Right now gcode send function is having issues that need resolution before anything else happens
    [Machine.py, Pipette.py, Tool.py]
2023-09-29 extensive debugging to get pipette and camera functional
2023-10-03 bug fixes mostly to machine base code and pipette module to get pipetting working correctly for demo. Lots of hacks and half fixes in this commit - todos mostly describe issues and what we thik the r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
    [Machine.py, Pipette.py]
2023-10-04 adding all fab files for OT2
    [OT_Post_Base.STL, OT_tool_holder.STL, OT_tool_plate.STL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]
2023-10-06 Converted OT2-pipette configuration instructions into .md file and added section on how to the pipette tip endstop to the config.g file
2023-10-09 Fixed config file handling for labware and deck files. Added order option for labware in class init
    [Machine.py]
2023-10-10 fixed duplicate code in a pipette method
    [Pipette.py]
2023-10-12 fixed static method to check for new Location class and modified functions to accomodate new change
    [Pipette.py]
2023-10-19 Fixed deck import commands as config file was getting initiated twice
    [Machine.py]
2023-11-08 add requests library to requirements, fix submodule paths
    [Machine.py]
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2023-11-21 Changed all path to package modules to absolute ones and removed redundant parameter to instantiate Pipette and Webcamera as base tool class takes care of it
2023-11-30 update syringe, camera, and loop tools with functions relevant for duckweed growth assays
    [calibration_checkerboard.yml]
2023-12-01 start work on peristaltic pump based dispense tool integration
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2023-12-05 update pippette to use utils getxyz function and remove this from pipette module
2023-12-06 debug switch to utils for some helper functions. Pipette changes tested on real-world machine with a dry run, moving to well and aspirating does not throw errors and generates correct xyz movement.
    [Pipette.py]
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2023-12-07 set default safe z for an empty science automation deck to be 10mm
2023-12-07 real world debug of peristaltic pump tool complete
2023-12-07 fix docstrings for pump tools
    [PeristalticPumps.py, PumpDispenser.py]
2023-12-12 Added contributors guidelines pages; docstrings for camera, loop, and syringe
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2023-12-12 Added docstrings to WebCamera module and included option to turn on LED ring light before image capture
2023-12-12 Fixed typos and incorrect parameter description
    [Pipette.py]
2024-01-18 Removed machine from Pipette tool definition as it is defined in class
2024-01-18 New Sonicator tool- adaptation of sonication_statio code and new implementation of Pico microcontroller communication interface
2024-01-18 Upload sonicator tool documentaion and schemaitics
    [sonicator_pi_hat.kicad_pcb, sonicator_pi_hat.kicad_sch, sonicator_tool_assembly.STEP]
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2024-01-26 Fixed module imports and removed unused ones. Added `tool_offset` to :class:`Tool` and removed attribute from Pipette and Webcamera tools
    [Pipette.py, Sonicator.py, Tool.py]
2024-01-30 Added method for 3-point manual offset applied to labware once loaded onto deck- better allignment between deck and carriage arm
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2024-02-01 Added documentation and .stl files for WebCamera tool
    [PiCamera_tool_plate.stl, RaspberryPi_Camera_V2_Tool.stl, RaspberryPi_Camera_V2_Tool_Ring_Light.stl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]
2024-02-16 Updated OT2 pipettor documentation and consolidated design files into single folder
    [OT2_Pipette_Wings.stl, OT_Post_Base.STL, OT_tool_holder.STL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]
2024-02-21 Fixed device usb initialization and light source connection
    [Spectrometer.py]
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2024-02-29 add tool parking post notebook
    [tfree.g, tpost.g, tpre.g]
2024-03-19 Added tip tracking streategy inspired by the Opentrons API and adapted it for more practical use of Science_Jubilee. Modified methods in Pipette class to match new changes
2024-03-21 Fixed bugs with Tip Tracking strategies and typos made during addition of new code
    [Pipette.py]
2024-03-25 Fixed post_laod method for Pipette to prime it for ready to use
    [Pipette.py]
2024-03-25 Fixed missing return statement
    [Pipette.py]
2024-03-26 fixed data type for mixing if Location is given instead of Well
    [Pipette.py]
2024-04-02 Deleted incorrect OT parking post base stl
    [OT_Post_Base.STL]
2024-04-02 Fixed import to work on different OS. Fixed init for Pico mode and included cleaning protocol stratergy
    [Sonicator.py]
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2024-04-12 fix tool lock/unlock macros
    [Machine.py]
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2024-04-18 gel extrusion updates + camera updates
    [calibration_checkerboard.yml]
2024-04-19 Scaled up OT Pipette guide rails for correct tool position on post and consolidaetd into single file
    [L&R_guide_rail.STL, left_guide_rail.STL, right_guide_rail.STL]
2024-04-19 Updaetd blowout and mix speed and lowered pipette return_tip height for better physical tip handling
2024-04-19 Fixed module import for different sonicator interfaces and finalized cleaning protocols
    [Sonicator.py]
2024-04-19 Fixed module import. Cleaned out lamp on/off logic. Updated MeasurementManager and included read_from_file method in tool
    [Spectrometer.py]
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2024-04-21 fix tool load/reload; update syringe extruder with a wipe method
    [Camera.py, Machine.py, SyringeExtruder.py]
2024-04-22 add G10 command to machine, update gel printing nb
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2024-04-23 fix move extrude in syringe extruder
    [SyringeExtruder.py]
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2024-04-23 Update Camera.py
    edit path for cam calibration file
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2024-04-25 Add updated OT assembly instructions
    changed tool wing screw length. everything else is the same.
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2024-04-27 mv and renames
    [agilent_1_reservoir_290ml.json, calibration_checkerboard.yml, tfree.g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]
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2024-05-08 add config.g file for functional color mixing demo
    [color_mixing_demo_config.g]
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2024-05-27 Update pipette_tool.md with correct link for wiring diagram
2024-05-29 split deps to optionals and environment.yml
    need to verify that imports can still work (i.e., files are separated in a way that import errors won't get thrown when trying to use e.g., non-camera functions)
2024-06-07 add example config files
    [bed.g, config.g, homeall.g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]
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2024-06-13 make editable pages for each assembly instruction packet
2024-06-13 remove config gcode files from PR
    [bed.g, config.g, homeall.g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]
2024-07-08 Add STL for deck top and bottom
    [deck_bottom.ipt, deck_bottom.stl, deck_top.ipt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]
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2024-07-16 bug fixes to syringe tool
    [HTTPSyringe.py]
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2024-08-24 bug fix related to speed function argument addition
    [HTTPSyringe.py]
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2024-10-10 Add documentation on tool ball sensor crash detection
2024-10-14 add initial logic to handle crash detected messages from jubilee
    [Handlers.py, Machine.py]
2024-10-14 bug fixes for crash detection handling
    [Machine.py]
2024-10-17 fix crash detection code
    [Machine.py]
2024-10-21 add http syringe docs and cads
    [cover_10cc v4.f3d, cover_10cc v4.step, cover_10cc v4.stl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]
2024-10-21 format step files. Cant figure out how to exclude from pre-commit so here we go
    [cover_10cc v4.step, cover_1cc v3.step, holder_10cc v2.step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]
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2025-03-22 Update pipette_tool.md
    Duplicate section header to section 2. Proposed new section 4 header for setting steps/mm and step type
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2025-03-27 fix inline docs for from_config + handle json file naming for convenience
    [Pipette.py]
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2025-03-31 fix pipette tip strategy for "never", add mix function back into syringe
    [Pipette.py]
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2025-04-01 Updated lab automation bed.g file
    Bed should be moved down after mesh bed compensation
    [bed.g]
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2025-05-22 update formatting
    [cover_1cc_hamilton v2.f3d, cover_1cc_hamilton v2.step, cover_1cc_hamilton v2.stl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]
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2026-03-31 reorganize tool configs
    [calibration_checkerboard.yml]
2026-04-01 fix transfer function for lists of volumes
    [Pipette.py]
2026-04-01 move config finder out of tool modules and fix syringe config loading
    [AS7341.py, PeristalticPumps.py, Pipette.py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]
2026-04-02 Consolidate three camera tools into unified Camera with backend strategy pattern
    - Replace Camera.py, WebCam.py, WebCamera.py with a single Camera class
    that supports opencv, http, and picamera backends via config
    - Extract hardware-agnostic image processing to utils/image_processing.py
    - Add config files: camera_opencv.json, camera_http.json, camera_picamera.json
    - Add CameraIntro.ipynb demo notebook
    - API: capture(), show_image(), record(), start_recording()/stop_recording()
    - Only the opencv backend with USB Arducam has been tested
    [Camera.py, image_processing.py]
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2026-04-21 fix camera release for cam tool
    [Camera.py]
